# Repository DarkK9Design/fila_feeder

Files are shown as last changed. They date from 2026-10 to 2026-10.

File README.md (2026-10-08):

# fila_feeder
An automatic filament feeder designed to simplify filament loading and unloading at the 3D printer toolhead using a Stealthburner toolhead board, a servo, and filament sensor to detect and feed filament to and from the toolhead. **DISCLAIMER:** It is still very much in beta. Read the comments on the [.CFG file](https://github.com/DarkK9Design/fila_feeder/blob/main/Macros/fila_feeder.cfg)



# CANBus configuration help
https://canbus.esoterical.online/

# Files to print
- [[a]_Lever_0.6.stl](https://github.com/DarkK9Design/fila_feeder/blob/main/CAD/STLs/[a]_Lever_0.6.stl)
- [[a]_PCB_Mount_0.2.1.stl](https://github.com/DarkK9Design/fila_feeder/blob/main/CAD/STLs/[a]_PCB_Mount_0.2.1.stl)
- [[a]_Secure_Cap_0.3.stl](https://github.com/DarkK9Design/fila_feeder/blob/main/CAD/STLs/[a]_Secure_Cap_0.3.stl)
- [Main_Plate_0.6.stl](https://github.com/DarkK9Design/fila_feeder/blob/main/CAD/STLs/Main_Plate_0.6.stl)
- [Bowden_In_0.7.1.stl](https://github.com/DarkK9Design/fila_feeder/blob/main/CAD/STLs/Bowden_In_0.7.1.stl)

**All files** are located on this GitHub in the [STLs folder](https://github.com/DarkK9Design/fila_feeder/tree/main/CAD/STLs)

# Print settings
All files are to be printed using 'VORON Standard' parts settings/filaments:
| 3D Printing Process: Fused Deposition Modeling (FDM) | Infill Type: Grid, Gyroid, Honeycomb, Triangle or Cubic |
|---|---|
| Material: ABS/ASA | Infill Percentage: 40% |
| Layer Height: 0.2mm | Wall Count: 4 |
| Extrusion width: Forced 0.4mm | Solid Top/Bottom Layers: 5 |
| x.x.1 Print files | Print with Tree Supports |

# Bill of Materials
| Category: | Part Description: | Qty: | Links | Notes |
|---|---|---|---|---|
| Fasteners | | | | |
| | M3x8 SHCS | 10 | https://a.co/d/037f3WVD | |
| | M3x8 FHCS | 1 | https://a.co/d/0hF9KEpC | |
| | M3x12 SCHS | 3 | https://a.co/d/05wmjjIP | |
| | M3x20 SCHS | 1 | https://a.co/d/07LzdmIO | |
| | M3x30 SCHS | 1 | https://a.co/d/07IOfGE3 | |
| | M3 Heat Set Insert (M3x5x4) | 8 | https://a.co/d/00ZfhXog | |
| | M3 T-Nut | 3 | https://a.co/d/071vCX4D | |
| | M2x12 SHCS | 2 | https://a.co/d/02RGdxsP | |
| Motion | | | | |
| | BMG Drive Gear Kit | 1 | https://a.co/d/01gLroWM | |
| Electronics | | | | |
| | Omron D2F-01F Micro Switch | 1 | https://a.co/d/0jkQkVP9 | |
| | NEMA17 Pancake Stepper Motor | 1 | https://a.co/d/00Iv0LOb | Could use any NEMA 17 stepper |
| | SB Toolhead Board | 1 | https://a.co/d/0isNCulj | Any similar board should work. Use the included connectors for cabling |
| | MG90S 9G Micro Servo | 1 | https://a.co/d/0gZUF8IG | Use the 21mm included arm |
| Misc. | | | | |
| | 6x3mm Neodimium Magnet | 2 | https://a.co/d/0f8KDar4 | |
| | 4mm Threaded Bowden Coupler | 2 | https://a.co/d/08kZ09dT | |
| | Loctite Blue Threadlocker Stick | 1 | https://a.co/d/00mKnUja | |
| | PTFE Tube (4mm OD 2.5mm ID) - 1000mm | 1 | https://a.co/d/00Jn22YE | |
| | PTFE Tube (4mm OD 2.5mm ID) - 50mm | 1 | https://a.co/d/00Jn22YE | |
| | 5mm steel ball-bearing | 1 | https://a.co/d/0a5YDpLx | |

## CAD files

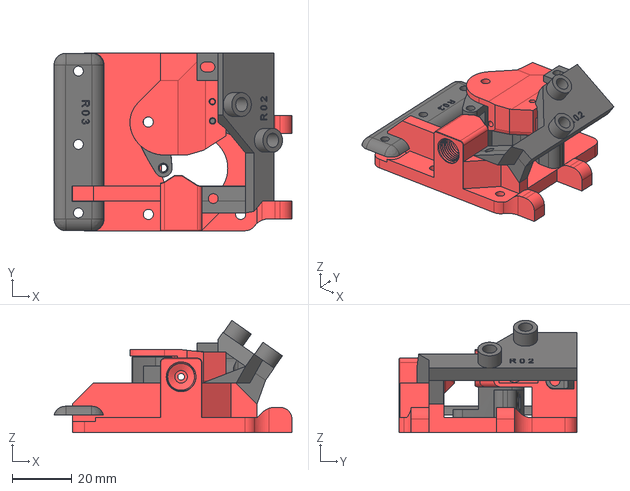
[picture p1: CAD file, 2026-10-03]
CAD/STEP/Fila_Feeder_assembly.step
79.9 x 59.6 x 37.7 mm

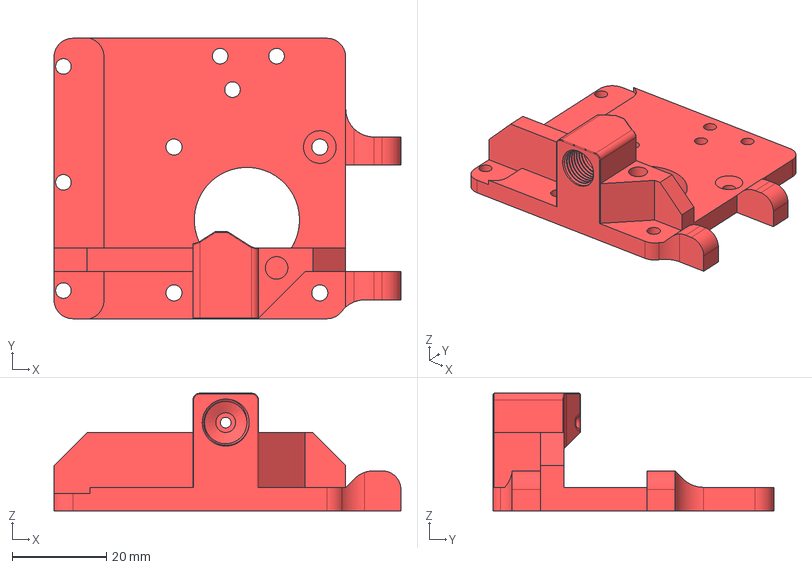
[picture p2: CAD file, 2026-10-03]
CAD/STEP/Main_Plate_0.6.step
73.8 x 59.6 x 25.0 mm

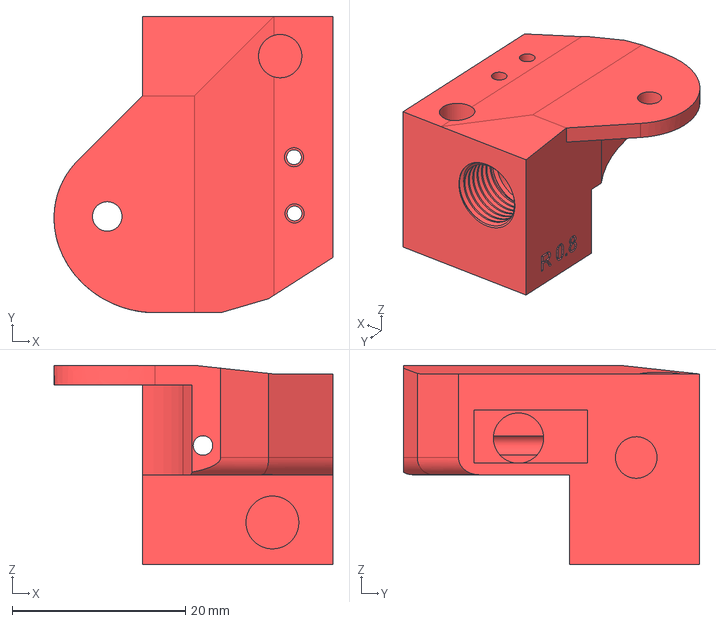
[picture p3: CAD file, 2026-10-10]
CAD/STEP/Bowden_In_0.8.step
32.2 x 34.2 x 23.0 mm

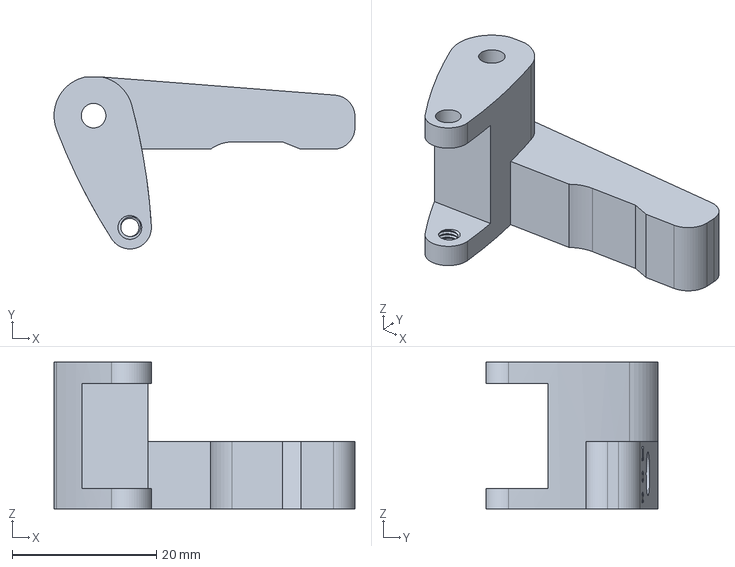
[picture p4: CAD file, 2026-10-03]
CAD/STEP/[a]_Lever_0.6.step
41.7 x 23.8 x 20.4 mm

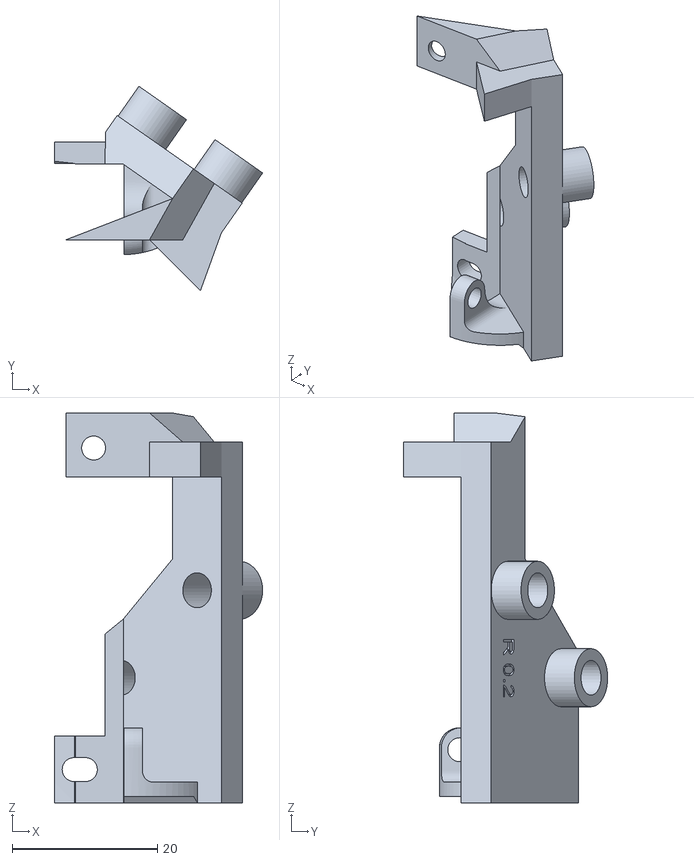
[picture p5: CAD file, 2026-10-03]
CAD/STLs/[a]_PCB_Mount_0.2.1.stl
28.6 x 28.1 x 53.6

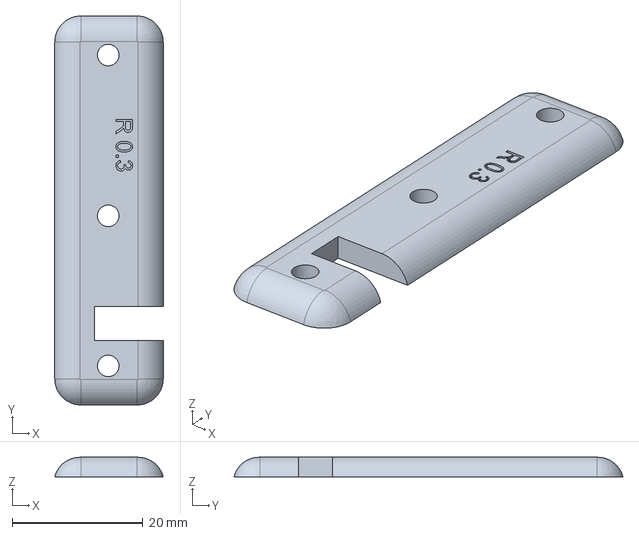
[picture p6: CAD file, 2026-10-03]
CAD/STEP/[a]_Secure_Cap_0.3.step
16.6 x 59.6 x 3.00 mm

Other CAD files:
CAD/STLs/Bowden_In_0.8.1.stl
CAD/STLs/Bowden_In_0.7.1.stl
CAD/STEP/Bowden_In_0.7.step
CAD/STLs/[a]_Lever_0.6.1.stl
CAD/STEP/[a]_PCB_Mount_0.2.step
CAD/Fila_Feeder.f3d
CAD/STLs/Bowden_In_0.7.stl
CAD/STLs/Main_Plate_0.6.stl
CAD/STLs/[a]_PCB_Mount_0.2.stl
CAD/STLs/[a]_Secure_Cap_0.3.stl

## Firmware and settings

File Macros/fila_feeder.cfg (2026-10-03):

# This file contains common pin mappings for the BIGTREETECH SB2209 RP2040 V1.0
# Canbus board. To use this config, the firmware should be compiled for the
# RP2040 with "USB" or "CAN bus (on gpio4/gpio5)".
# The "EBB Can" micro-controller will be used to control the components on the nozzle.

# See docs/Config_Reference.md for a description of parameters.
[force_move]
enable_force_move: True

[mcu Feeder]
canbus_uuid: YOU_DIDNT_CHANGE_ME_YET

[temperature_sensor Feeder_NTC]
sensor_type: Generic 3950
sensor_pin: Feeder:gpio28

[filament_switch_sensor filament_feeder]
switch_pin: ^Feeder:gpio24
pause_on_runout: False
insert_gcode:
    M117 Insert Detected
    SET_HEATER_TEMPERATURE HEATER=extruder TARGET=150
    SET_SERVO SERVO=fil_servo ANGLE=17 # servo gripping filament
    ACTIVATE_EXTRUDER EXTRUDER=extruder1 # activates fila_feeder stepper
    _CLIENT_LINEAR_MOVE E=950 F=5000
    FORCE_MOVE STEPPER=extruder DISTANCE=20 VELOCITY=10 # forces toolhead to grab filament
    SET_SERVO SERVO=fil_servo ANGLE=45 # servo not gripping filament
    ACTIVATE_EXTRUDER EXTRUDER=extruder # activates toolhead extruder
    LOAD_FILAMENT
runout_gcode:
    

# [adxl345]
# cs_pin: Feeder:gpio1
# spi_software_sclk_pin: Feeder:gpio2
# spi_software_mosi_pin: Feeder:gpio0
# spi_software_miso_pin: Feeder:gpio3
# axes_map: z,-y,x

# [resonance_tester]
# probe_points: 100, 100, 20
# accel_chip: adxl345

[servo fil_servo]
pin: Feeder:gpio22
maximum_servo_angle: 180
minimum_pulse_width: 0.001
maximum_pulse_width: 0.002
initial_angle: 90

[extruder1]
step_pin: Feeder:gpio18
dir_pin: !Feeder:gpio19
enable_pin: !Feeder:gpio17
microsteps: 16
rotation_distance: 23.0482278
nozzle_diameter: 0.400
filament_diameter: 1.750
heater_pin: Feeder:gpio7
sensor_type: EPCOS 100K B57560G104F
sensor_pin: Feeder:gpio27
min_extrude_temp: -200
max_extrude_only_distance: 970.0
control: pid
pid_Kp: 21.527
pid_Ki: 1.063
pid_Kd: 108.982
min_temp: -200
max_temp: 250

# sensor_type: MAX31865
# sensor_pin: Feeder:gpio9
# spi_software_sclk_pin: Feeder:gpio10
# spi_software_mosi_pin: Feeder:gpio8
# spi_software_miso_pin: Feeder:gpio11
# rtd_nominal_r: 100
# rtd_reference_r: 430
# rtd_num_of_wires: 2

[tmc2209 extruder1]
uart_pin: Feeder:gpio20
run_current: 0.650
stealthchop_threshold: 999999

# [fan]
# pin: Feeder:gpio13

# [heater_fan hotend_fan]
# pin: Feeder:gpio14
# heater: extruder
# heater_temp: 50.0

# [fan_generic 4W_FAN0]
# pin: Feeder:gpio15
# tachometer_pin: Feeder:gpio12
# #tachometer_ppr: 1

# [neopixel hotend_rgb]
# pin: Feeder:gpio16

# [bltouch]
# sensor_pin: ^Feeder:gpio21
# control_pin: Feeder:gpio22

## NPN and PNP proximity switch types can be set by jumper
#[probe]
#pin: ^Feeder:gpio6

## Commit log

2026-10-04 Added T-Nuts to BOM
    [Fila_Feeder_BOM.xlsx]
2026-10-04 Update README.md
    Added T-Nuts to BOM
    Added file-specific print instructions
2026-10-08 Update README.md - updated BOM
2026-10-10 Updated filament sensor bearing path
    [Bowden_In_0.8.1.stl]
